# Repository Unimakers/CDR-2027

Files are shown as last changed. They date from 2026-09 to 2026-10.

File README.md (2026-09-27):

# Coupe de France de Robotique 2027 - Unimaker I1/I2

> [!IMPORTANT]
> Ce repo a été créé depuis le template de projet du MakerSpace d'Amiens.
> Les guides d'utilisation du template sont sur le
> [site de documentation du MakerSpace](https://doc.makerspace-amiens.fr/workshops/methodologie-de-projet/).

Ce repo est un site de documentation réalisé par l'équipe des première et deusième années pré-ingénieur de l'école Unilasalle-Amiens, membre de l'association de robotique Unimaker, dans le cadre de leur participation à la Coupe de France de Robotique 2027 (CDR 2027).
Cette documentation sera mise à jour tout au long de l'année à chaque étape du projet.

- **Documentation :** [site du projet](https://unimakers.fr/CDR-2027/) (sources dans [`docs/`](docs/))
- **Fichiers du projet :** [`project/`](project/) (CAO, électronique, code)

## Équipe

### Étudiants de deuxième année

- Ajaz Agbetiafa
- Baptiste Houzelot
- Brett Legret
- Emma Vilain
- Emrick Petit
- Enzo Deviliers
- Gauthier Henriques
- Martin Milon
- Paul Lapeyronnie
- Romain Vantalon
- Samuel Simao

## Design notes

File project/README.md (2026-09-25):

# Fichiers du projet

> [!IMPORTANT]
> **À modifier** : complétez ce README avec ce que contient réellement votre projet.

Ce dossier contient toutes les **sources** du projet. Ce qui s'affiche sur le site
(images, modèle 3D `.glb`, copie des fichiers KiCad) va dans `docs/assets/`.

| Dossier | Contenu |
|---|---|
| [`mcad/`](mcad/) | Conception mécanique : exports STEP, fichiers d'impression 3D et de découpe laser |
| [`ecad/`](ecad/) | Conception électronique : projets KiCad |
| [`firmware/`](firmware/) | Code embarqué (Arduino, ESP32…) |
| [`software/`](software/) | Application sur ordinateur, téléphone ou web |

Supprimez les dossiers qui ne concernent pas votre projet.

**Noms de fichiers :** pas d'espaces ni d'accents (`support-moteur.step`, pas
`Support Moteur.step`), ils cassent les liens du site.

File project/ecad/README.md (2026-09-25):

# Conception électronique

> [!IMPORTANT]
> **À modifier** : décrivez les cartes de votre projet.

Un dossier par projet KiCad (par exemple `carte-principale/`), contenant au minimum
les fichiers `.kicad_pro`, `.kicad_sch` et `.kicad_pcb`.

| Carte | Dossier | Rôle |
|---|---|---|
| Carte principale | `carte-principale/` | Microcontrôleur, alimentation, connecteurs |

Pour afficher une carte sur le site, copiez ses fichiers `.kicad_sch` et `.kicad_pcb`
dans `docs/assets/kicad/`, et recopiez-les quand la carte évolue.

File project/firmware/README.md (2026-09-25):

# Firmware

> [!IMPORTANT]
> **À modifier** : décrivez le firmware de votre projet, ou supprimez ce dossier s'il n'y en a pas.

Le **firmware** est le code qui tourne sur la carte électronique (Arduino, ESP32, Raspberry Pi Pico…).
Il se développe avec **VSCode** et l'extension **PlatformIO**
(voir [Installation de VSCode et PlatformIO](https://doc.makerspace-amiens.fr/docs/tutorials/software/vscode-platformio/installation-vscode/)).

- **Carte cible :** …
- **Bibliothèques :** listées dans `platformio.ini` (`lib_deps`), avec leur version

## Organisation

Un dossier par projet PlatformIO :

```text
firmware/
└── mon-robot/
    ├── platformio.ini    carte, framework, bibliothèques
    ├── src/
    │   └── main.cpp      programme principal
    ├── include/          fichiers .h
    └── lib/              bibliothèques écrites par l'équipe
```

Le dossier `.pio/` (fichiers de compilation) est ignoré par git : ne le commitez pas.

## Compiler et téléverser

1. Dans VSCode, ouvrez le dossier du projet PlatformIO (`File > Open Folder` sur
   `firmware/mon-robot/`), pas la racine du repo : sinon PlatformIO ne détecte pas le projet.
2. Branchez la carte en USB.
3. Dans la barre du bas : **✓** pour compiler, **→** pour téléverser, **🔌** pour ouvrir le moniteur série.

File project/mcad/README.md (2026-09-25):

# Conception mécanique

> [!IMPORTANT]
> **À modifier** : renseignez le lien Onshape et la date du dernier export.

- **Document Onshape :** [lien de partage](https://cad.onshape.com/)
- **Dernier export :** AAAA-MM-JJ

## Contenu

| Fichier / dossier | Contenu |
|---|---|
| `projet.step` | Export STEP de l'assemblage complet (lisible par tous les logiciels de CAO) |
| [`3d-print/`](3d-print/) | Fichiers pour l'impression 3D |
| [`laser-cutting/`](laser-cutting/) | Fichiers pour la découpe laser |

Le modèle 3D affiché sur le site (`.glb`) ne va pas ici mais dans `docs/assets/models/`.

## Exporter depuis Onshape

- **STEP :** clic droit sur l'onglet de l'assemblage > Exporter > format STEP, à enregistrer ici sous `projet.step`.
- **GLB (pour le site) :** même menu, format GLB, à enregistrer dans `docs/assets/models/`.

Réexportez à chaque version importante : Onshape garde l'historique, mais le repo
doit contenir une version utilisable sans compte Onshape.

## Autre logiciel (Fusion, SolidWorks, FreeCAD…)

Déposez ici les fichiers natifs **en plus** de l'export STEP : contrairement à
Onshape, ils ne sont sauvegardés nulle part ailleurs.

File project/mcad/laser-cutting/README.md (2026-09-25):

# Découpe laser

> [!IMPORTANT]
> **À modifier** : complétez le tableau pour chaque pièce, puis supprimez cette ligne.

Déposez ici les fichiers de découpe (`.svg` ou `.dxf`).

| Pièce | Fichier | Matériau | Épaisseur | Quantité |
|---|---|---|---|---|
| Boîtier | `boitier.svg` | Contreplaqué peuplier | 3 mm | 1 |

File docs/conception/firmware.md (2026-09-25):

---
layout: default
title: Firmware
parent: Conception
nav_order: 3
---

# Firmware

{: .a_supprimer }
> Le **firmware** est le code qui tourne sur la carte électronique (Arduino, ESP32,
> Raspberry Pi Pico…) : il lit les capteurs, pilote les actionneurs, gère les
> communications. Supprimez cette page si votre projet n'en a pas.
> Si le code est conséquent, faites une sous-page par fonction (par exemple
> « Asservissement moteur », « Communication Bluetooth »).
> Voir [Documenter son code et son firmware](https://doc.makerspace-amiens.fr/workshops/methodologie-de-projet/tutorials/documenter-code-firmware/).

## Architecture du code

{: .a_modifier }
> Fonctionnement général : boucle principale, machine à états, interruptions.
> Un schéma (diagramme d'états, organigramme) aide beaucoup.

## Environnement

{: .a_modifier }
> Carte cible, framework (Arduino, ESP-IDF…), bibliothèques principales et leur rôle.
> Le projet se développe avec VSCode et PlatformIO : la procédure pour compiler
> et téléverser est dans le README du dossier firmware.

[📁 Code du firmware]({{ site.gh_edit_repository }}/tree/main/project/firmware){: .btn }

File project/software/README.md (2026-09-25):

# Software

> [!IMPORTANT]
> **À modifier** : décrivez l'application de votre projet, ou supprimez ce dossier s'il n'y en a pas.

Le **software** est l'application qui tourne sur un ordinateur, un téléphone ou un
navigateur (interface de contrôle, traitement de données…).

- **Langage :** …
- **Dépendances :** …

## Installer et lancer

1. …

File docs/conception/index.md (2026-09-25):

---
layout: default
nav_order: 5
title: Conception
has_children: true
---

# Conception

{: .a_supprimer }
> **Une page par sous-système, pas une seule page pour toute la conception.**
> Ce template propose un découpage par domaine (mécanique, électronique,
> firmware, software) avec un exemple de sous-système dans les deux premiers. Adaptez-le à votre projet :
> - dupliquez une page d'exemple pour chaque sous-système (pince, châssis, carte capteurs…) ;
> - renommez ou supprimez les domaines qui ne vous concernent pas ;
> - si votre projet s'y prête mieux, découpez d'abord par sous-système, puis par domaine.
>
> Une sous-page se déclare avec `parent:` (et `grand_parent:` au niveau en dessous)
> dans son en-tête : inspirez-vous des pages d'exemple.

## Architecture globale

{: .a_modifier }
> Présentez le projet découpé en sous-systèmes : un schéma bloc (image) et une phrase
> par bloc suffisent. Qui communique avec qui ? Qu'est-ce qui alimente quoi ?
> Exemple : le schéma ci-dessous est écrit en texte avec [Mermaid](https://mermaid.js.org/) :
> modifiez-le directement dans le fichier, ou remplacez-le par une image réalisée
> avec l'outil de votre choix (draw.io, Inkscape, papier scanné…).

```mermaid
graph LR
    Batterie[Batterie] --> Carte[Carte principale]
    Capteur[Capteur de couleur] --> Carte
    Carte --> Moteur[Moteur du trieur]
    Carte <-->|Bluetooth| Appli[Application mobile]
```

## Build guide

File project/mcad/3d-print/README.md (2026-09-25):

# Impression 3D

> [!IMPORTANT]
> **À modifier** : complétez le tableau pour chaque pièce, puis supprimez cette ligne.

Déposez ici les fichiers prêts à imprimer (`.3mf` de préférence, il conserve les réglages du slicer).

| Pièce | Fichier | Matériau | Buse | Couche | Remplissage | Supports | Quantité |
|---|---|---|---|---|---|---|---|
| Support moteur | `support-moteur.3mf` | PLA | 0,4 mm | 0,2 mm | 20 % | Non | 2 |

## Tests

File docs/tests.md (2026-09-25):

---
layout: default
nav_order: 7
title: Tests et résultats
---

# Tests et résultats

{: .a_supprimer }
> Cette page apporte la **preuve** que votre projet répond au cahier des charges.
> Reprenez les critères de la page **Objectifs du projet** et écrivez un protocole
> de test pour chacun, puis notez les résultats, **y compris les échecs**.
> Voir [Documenter les tests et résultats](https://doc.makerspace-amiens.fr/workshops/methodologie-de-projet/tutorials/documenter-tests-resultats/).

## Synthèse

{: .a_modifier }
> Un tableau récapitulatif des critères testés. Exemple :

| Critère | Attendu | Mesuré | Validé |
|---|---|---|---|
| Taux de tri correct | ≥ 80 % sur 20 essais | 85 % | ✅ |
| Autonomie sur batterie | ≥ 4 h | 3 h 30 | ❌ |

## Test : taux de tri correct

{: .a_modifier }
> Exemple de protocole : dupliquez cette section pour chaque critère testé.

**Critère visé :** ≥ 80 % sur 20 essais (voir le cahier des charges).

**Méthode :** déposer 20 déchets connus un par un, noter la catégorie détectée.

**Conditions :** éclairage de la salle d'exposition, température ambiante.

| Essai | Déchet réel | Détection | Correct ? |
|---|---|---|---|
| 1 | Plastique | Plastique | ✅ |
| 2 | Verre | Métal | ❌ |
| … | … | … | … |

**Résultat :**

$$
\tau = \frac{n_{\text{corrects}}}{n_{\text{essais}}} = \frac{17}{20} = 85\,\%
$$

Critère atteint. Les 3 erreurs concernent des bouteilles en verre teinté.

## Test : autonomie sur batterie

{: .a_modifier }
> Les formules s'écrivent en LaTeX entre `$$` : seules sur leur ligne (avec une
> ligne vide avant et après) elles sont centrées, dans une phrase elles restent
> dans le texte. Le `$` simple ne fonctionne **pas** sur le site.

Avec une batterie de capacité $$C = 2000\ \text{mAh}$$ et un courant moyen
mesuré de $$I_{\text{moy}} = 570\ \text{mA}$$, l'autonomie théorique vaut :

$$
t = \frac{C}{I_{\text{moy}}} = \frac{2000}{570} \approx 3{,}5\ \text{h}
$$

Mesurée : 3 h 30, critère non atteint (≥ 4 h). Piste : mise en veille du capteur
entre deux déchets.

{% include graphique.html csv="assets/data/decharge-batterie.csv" titre="Décharge de la batterie" y="Tension (V)" %}

{: .a_modifier }
> Le graphique est tracé à partir du fichier `docs/assets/data/decharge-batterie.csv` :
> première colonne pour l'axe X, une colonne par courbe, les noms des colonnes
> servent de légende. Exportez vos mesures en CSV (tableur, moniteur série…),
> placez le fichier dans `docs/assets/data/` et changez le nom dans l'include.
> Options : `type="bar"` pour un histogramme, `type="scatter"` pour des points seuls.

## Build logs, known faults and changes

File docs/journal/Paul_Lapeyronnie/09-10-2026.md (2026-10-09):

---
layout: default
title: "09-10-2026 : lancement"
parent: Paul_Lapeyronnie
grand_parent: Journal de bord
---

# carte élec
### j'ai mis les pins dans le bon ordre pour avoir aucun croisement et ça rend bien.
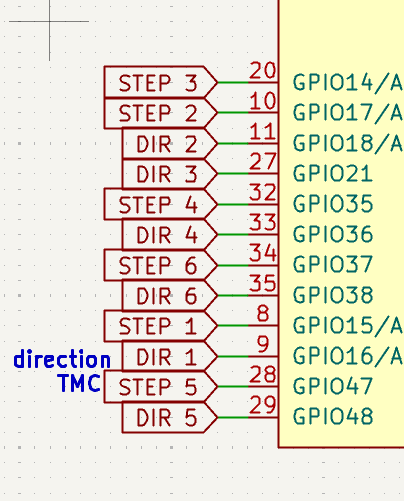
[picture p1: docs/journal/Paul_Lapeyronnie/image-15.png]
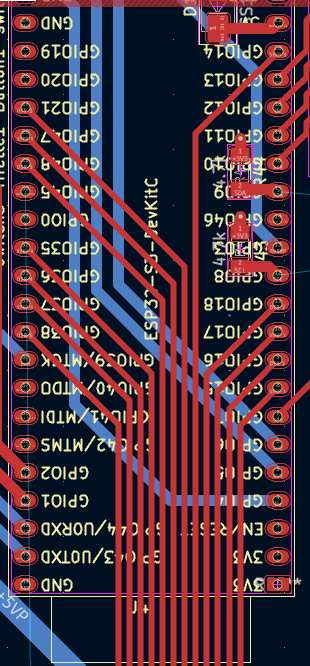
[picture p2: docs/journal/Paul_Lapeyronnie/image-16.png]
### 

### j'ai aussi relierles dernier élément comme ecrans, sda scl, tirette boutton ..., Eneble.

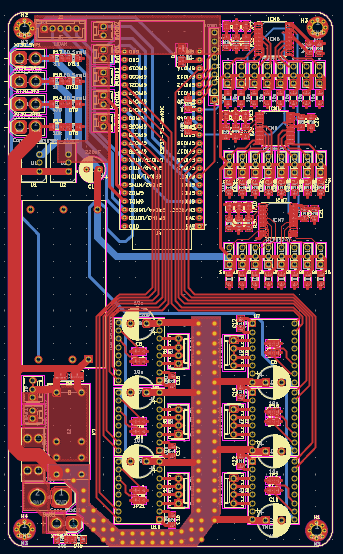
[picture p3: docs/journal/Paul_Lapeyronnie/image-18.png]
### 
### victoire !!! (jai pas encore verif avec alban)
### j'ai demandé a alban c'est pas fini j'ai des truc a faire :=(
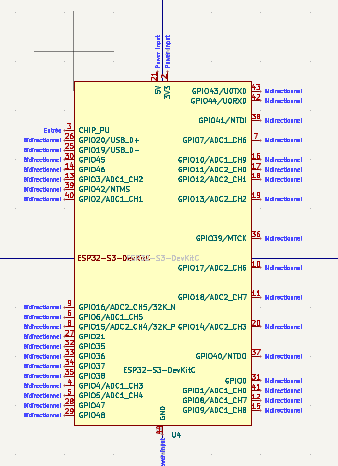
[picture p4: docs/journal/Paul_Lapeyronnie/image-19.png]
### 
### j'ai modif tous les pins pour que cela arrive de manière logique sur le routage

## ce dont je ne suis pas trop content
- le détoure du enable n'est pas beau 
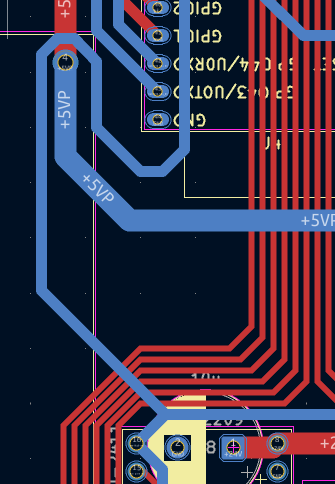
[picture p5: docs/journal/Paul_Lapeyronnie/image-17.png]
### 
- sda scl fait un détoure chelou

# module devkit c1
## y a t'il de pins spi non utilisable ?
### non après avoir regarder la datasheet, les pins 27 a 35 sont utiliser pour la psram/ quad spi flash, mais ils ne sont pas connecter au pins du module donc pas d'inquiétude 
### chill

## fun fact
### dans le module Esp il y a le vrais composant esp ainsi que des composants basique qui permettent de faire fonctionner le composant esp, le module contien aussi une antenne et un blindage pour les composants afin d'empecher le cristal de ce prendre les rayonnement de l'entaine.
### le composant de base esp a plein de pin gpio, usb, gnd, 3v3 ... ainsi que une certaine quantitée de mémoire ram et flash. Si on en veux plus, on doit utiliser des pin (gpio) pour en ajouter par exemle sur le devkit, on utilise : 
- sck = clok
- sdi = com
- sdo = com
- sc = select
### comme on utilise ces pin pour ajouter de la mémoire on ne peut pas les utiliser pour autre chose sans modifier la mémoire flsh/ram, sur le devkit ils ne sont pas relier au pins externes

# fun fact
### les via c'est en 0.7, 0.4 !

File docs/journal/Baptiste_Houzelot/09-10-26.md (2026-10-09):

---
layout: default
title: 09-10-26
parent: Baptiste_Houzelot
has_children: true
---

# Realisation du schema de l'actionneur
## Matériels nécessaires : 
- 1 cervo-moteur 
- 2 pompes 
- 1 moteur stepper
- 1 courroie

## Idées : 
### Prendre 3 cartons en une fois avec les pompes, tourner le support des pompes selon quel construction on doit faire et les placer. 
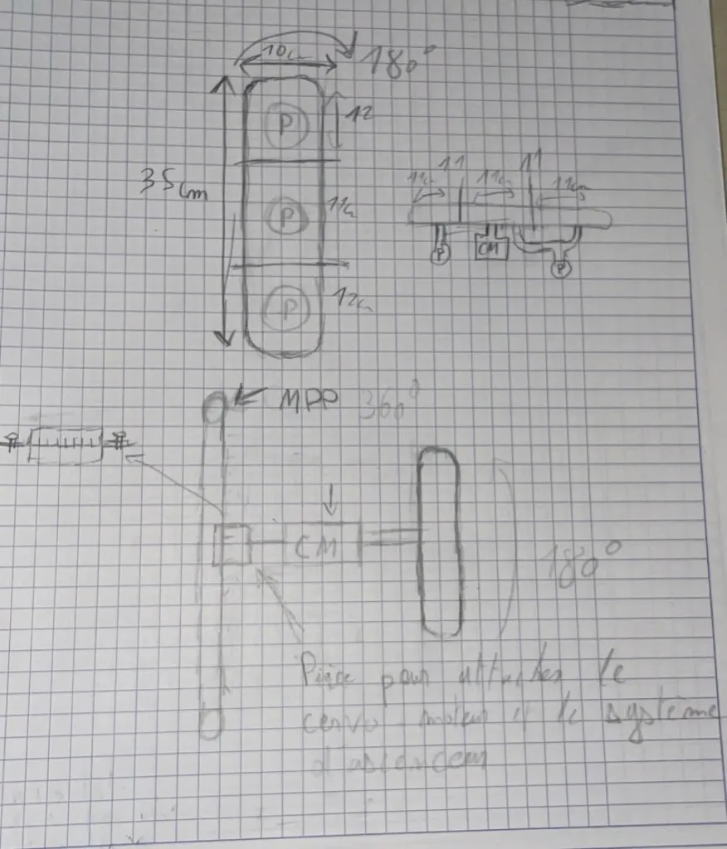
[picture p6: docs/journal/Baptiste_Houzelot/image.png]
###

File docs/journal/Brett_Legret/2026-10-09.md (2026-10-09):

---
layout: default
title: "2026-10-09 : conception d'actionneur version final" 
parent: Brett_Legret
grand_parent: Journal de bord
---

# 2026-10-09 : Conception de l'actionneur version final avant la modélisation:
---

a séance a débuté par une analyse de l'environnement de jeu de l'édition 2027.
⚬	Nous avons utilisé un simulateur 3D en ligne (visible dans le fichier Capture d’écran 2026-10-09 à 09.47.34.png) pour visualiser la table, les zones de départ et l'agencement des éléments de jeu.
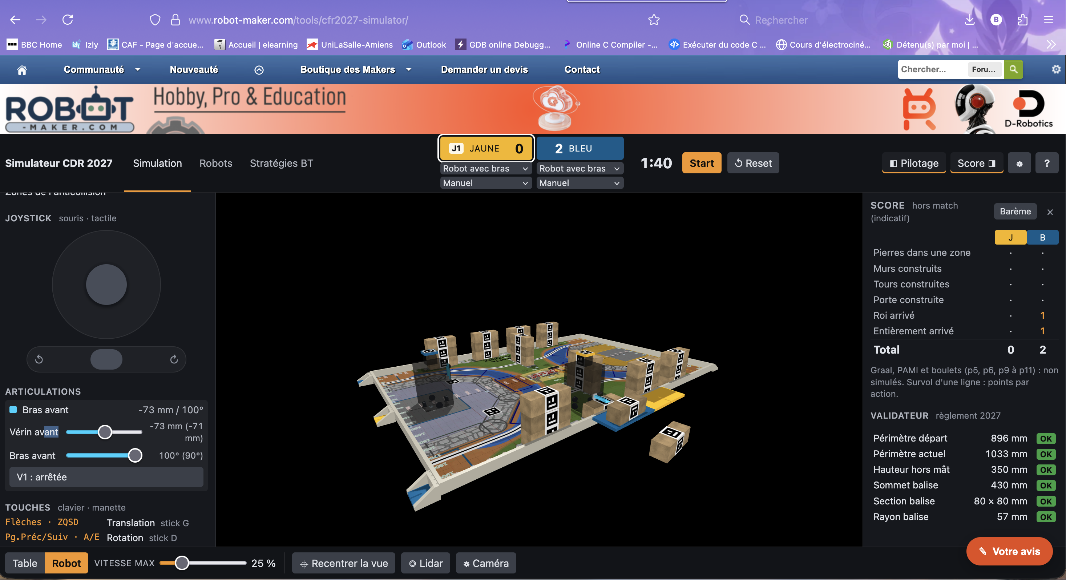
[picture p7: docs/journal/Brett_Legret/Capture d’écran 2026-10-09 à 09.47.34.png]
### 
⚬	Afin de bien cibler nos actions et d'éviter les erreurs, nous avons réétudié le règlement officiel "Eurobot2027_Rules_FR.pdf" (comme le montre le fichier Capture d’écran 2026-10-09 à 09.52.19.png). Nous nous sommes concentrés particulièrement sur la figure 6 détaillant le plan de construction du château avec les blocs.
2. Idéation et conception de l'actionneur
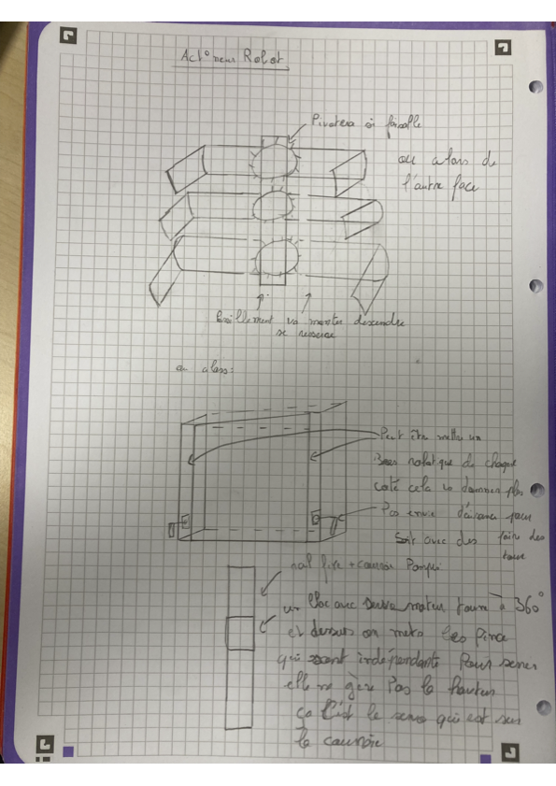
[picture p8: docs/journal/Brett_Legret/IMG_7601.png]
### 
Pour répondre aux défis imposés par le terrain, la deuxième partie de la séance a été consacrée au brainstorming sur le système mécanique du robot. Plusieurs concepts ont été dessinés et documentés sous le titre "Actionneur Robot". Voici les trois idées principales qui ont émergé :
⚬	Concept A (Mécanisme central) : Un système de préhension capable de se resserrer pour attraper les objets, de monter et descendre, avec l'idée d'ajouter un pivot ("pivotera si faisable") ou d'agir depuis "l'autre face".
⚬	Concept B (Bras latéraux) : Une structure en forme de boîte proposant d'intégrer un bras robotique de chaque côté. Cette configuration aurait pour but de donner davantage d'aisance au robot pour effectuer des rotations.
⚬	Concept C (Rail et courroie - Piste privilégiée) : L'utilisation d'un rail fixe couplé à une courroie. Le concept repose sur un bloc équipé d'un servomoteur capable de tourner à 360°, sur lequel reposent des pinces indépendantes. L'avantage de ce système est de séparer les efforts : les pinces gèrent uniquement le serrage, tandis que la hauteur n'est pas gérée par les pinces mais par un système sur la courroie.
3. Choix des composants et motorisation de l'actionneur
Pour donner vie à notre concept de préhension sur rail (Concept C), nous avons défini la nomenclature des moteurs nécessaires. Il nous faudra au total 6 moteurs, avec des rôles bien distincts pour séparer les efforts :
⚬	Élévation (2 moteurs pas à pas) : Nous utiliserons deux moteurs pas à pas dont le rôle exclusif sera de faire monter et descendre le système via la poulie et la courroie sur le rail fixe.
⚬	Rotation et Préhension (4 servomoteurs) : Ces moteurs seront embarqués sur le bloc mobile et serviront à manipuler les objets :
⚬	Faire pivoter le bloc pour orienter les pièces.
⚬	Serrer les pinces pour attraper les éléments de jeu de façon indépendante.
Bilan de la séance :
Nous avons une vision claire des objectifs (manipulation et empilage pour le château) et nous avons posé des bases mécaniques solides pour l'actionneur. La prochaine étape sera de commencer à modéliser ce système pour intégrer les 6 moteurs.

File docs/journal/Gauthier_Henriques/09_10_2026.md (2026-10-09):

---
layout: default
title: "08-10-2026 : Code robot principale"
parent: Gauthier_Henriques
grand_parent: Journal de bord
---

# 07-10-2026 : Dev

**Séance :** programé · **Durée :** 3h

## QUI FAIT QUOI
    - BRETT : actionneur
    - BAPTISTE : actionneur

Note sur les actionneurs pour préparer le code
    - 4 stepper pour les actionneurs
    - 24 servo / pompe total répartit sur 3 lignes de 8
    - un code actionneur, contrôle tout type

Note code: rester modulaire, multifichier, 
- étape 1 : rouler 
- étape 2 : LiDar
- étape 3 : tirette
- étape 4 : Actionneur
- étape 5 : switch (potentiellement avec 2/4)
- étape 6 : screen si on a le temps, pas obligatoire

Spi : buse de com
- SCK transfer clock
- SDI : input 
- SDO : output
- CS : chip select
Cahque elmeent sur le bus à un CS, microco a flash (stockage) et ram (vive) 
on peut ajouter de la psram (augmenter ram)
Quad SPI limite vitesse de com - donc octal SPI (8 lignes de donnés, 11 broches ) donc on mange sur Gpio
dans module wroom - composant esp32 s3 (on a pas le matos pour souder le composant donc on achete le module [valider par espressif])

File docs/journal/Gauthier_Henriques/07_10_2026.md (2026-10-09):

---
layout: default
title: "07-10-2026 : Code robot principale"
parent: Gauthier_Henriques
grand_parent: Journal de bord
---

# 07-10-2026 : Dev

**Séance :** Contrat-d'étude · **Durée :** 1 h 30

## Différence software vs firmware :
> software : haut niveau, fonctionne sur un OS.
> firmware : software de bas niveau, fonctionne de façon permanente ou semi-permanente sur un microcontroleur, controle les fonctions core du dit.

## Fait :
J'ai mis en place une config modulable pour le robot principale. Afin que tout les actionneurs puisse être tranférer sans probleme

Fichier : [`project/firmware/Firmware_Robot_Principale/src/config.h`](https://github.com/Unimakers/CDR-2027/blob/main/project/firmware/Firmware_Robot_Principale/src/config.h)

```mermaid
flowchart LR
    ESP[ESP32-S3<br/>config.h] --> STP[6x TMC2209<br/>STEP / DIR]
    ESP --> PWR[EN 5VP<br/>servos]
    ESP --> I2C[I2C<br/>3x PCF8574]
    ESP --> TFT[Écran TFT<br/>SPI]
    ESP --> IN[Tirette, bouton,<br/>3 switchs]
    ESP --> LID[LiDAR LD06<br/>UART + PWM]
```

```cpp
// Configuration file for the robot firmware
// Pin names come from the KiCad schematic "carte principale" (ESP32-S3-DevKitC, U4).
// All pins are placeholders (-1) until assigned; the schematic GPIO is given in the comments.

#pragma once

// Serial debug output
#define DEBUG_SERIAL true

// match duration
#define MATCH_DURATION 100 // in seconds

// ---------------------------------------------------------------------------
// Stepper drivers (TMC2209 U5..U10, 24V), driven with FastAccelStepper
// Pins are meant for engine.stepperConnectToPin(STEP_x_PIN) and
// stepper->setDirectionPin(DIR_x_PIN). The TMC2209 ~EN pins are not wired to the ESP32.
// ---------------------------------------------------------------------------
#define STEPPER_COUNT 6

#define STEP_1_PIN -1 // schematic: GPIO14
#define DIR_1_PIN -1  // schematic: GPIO17
#define STEP_2_PIN -1 // schematic: GPIO18
#define DIR_2_PIN -1  // schematic: GPIO21
#define STEP_3_PIN -1 // schematic: GPIO35
#define DIR_3_PIN -1  // schematic: GPIO36
#define STEP_4_PIN -1 // schematic: GPIO37
#define DIR_4_PIN -1  // schematic: GPIO38
#define STEP_5_PIN -1 // schematic: GPIO15
#define DIR_5_PIN -1  // schematic: GPIO16
#define STEP_6_PIN -1 // schematic: GPIO47
#define DIR_6_PIN -1  // schematic: GPIO48

// Motion parameters (placeholders)
#define STEPPER_STEPS_PER_REV -1       // full steps per motor revolution
#define STEPPER_MICROSTEPS -1          // set by the TMC2209 MS1/MS2 configuration
#define STEPPER_MAX_SPEED_HZ -1        // for setSpeedInHz(), in steps/s
#define STEPPER_ACCELERATION -1        // for setAcceleration(), in steps/s^2

// ---------------------------------------------------------------------------
// Power
// ---------------------------------------------------------------------------
#define EN_5VP_PIN -1 // enable of the 5VP (servo) converter, schematic: GPIO3

// ---------------------------------------------------------------------------
// I2C bus (3x PCF8574T I/O expanders ICM6..ICM8, J2 connector)
// ---------------------------------------------------------------------------
#define I2C_SDA_PIN -1 // schematic: GPIO9
#define I2C_SCL_PIN -1 // schematic: GPIO8

// PCF8574 addresses (set by the A0..A2 jumpers)
#define PCF_ICM6_ADDR -1
#define PCF_ICM7_ADDR -1
#define PCF_ICM8_ADDR -1

// ---------------------------------------------------------------------------
// TFT screen (J1, SPI, no reset line on the schematic)
// ---------------------------------------------------------------------------
#define TFT_MISO_PIN -1 // "sdo", schematic: GPIO7
#define TFT_MOSI_PIN -1 // "sdi", schematic: GPIO11
#define TFT_SCK_PIN -1  // "sck", schematic: GPIO10
#define TFT_DC_PIN -1   // "dc",  schematic: GPIO12
#define TFT_CS_PIN -1   // "cs",  schematic: GPIO13

// ---------------------------------------------------------------------------
// Inputs
// ---------------------------------------------------------------------------
#define TIRETTE_PIN -1 // starting cord, "tir", schematic: GPIO2
#define BUTTON_PIN -1  // push button, "bu", schematic: GPIO4
#define SWITCH_1_PIN -1 // "sw1", schematic: GPIO5
#define SWITCH_2_PIN -1 // "sw2", schematic: GPIO6
#define SWITCH_3_PIN -1 // "sw3", schematic: GPIO1

// ---------------------------------------------------------------------------
// LIDAR (J5, LD06 library in src/ld06.h)
// The LD06 is wired on the ESP32 UART0 pins (GPIO43/44), shared with the USB-UART bridge.
// Constructor: LD06(HardwareSerial &serial, LD06_PWM_PIN); init() calls serial.begin(230400) itself.
// ---------------------------------------------------------------------------
#define LD06_PWM_PIN -1 // motor PWM, "pwm", schematic: GPIO39 (255 = no PWM pin for the library)
#define LD06_RX_PIN -1  // ESP32 RX <- LD06 TX, schematic: GPIO44 (U0RXD)
#define LD06_TX_PIN -1  // ESP32 TX -> LD06 RX, schematic: GPIO43 (U0TXD)
#define LD06_UART_NUM -1 // HardwareSerial number to use for the LIDAR
#define LD06_BAUDRATE 230400 // fixed by the LD06 and by LD06::init()

// Filtering (see setDistanceRange / setAngleRange / setIntensityThreshold)
#define LD06_MIN_DISTANCE -1  // in mm
#define LD06_MAX_DISTANCE -1  // in mm
#define LD06_MIN_ANGLE -1     // in degrees
#define LD06_MAX_ANGLE -1     // in degrees
#define LD06_INTENSITY_THRESHOLD -1 // 0-255
#define LD06_UPSIDE_DOWN false

// Lidar position relative to the robot center (see setOffsetPosition)
#define LD06_OFFSET_X -1     // in mm
#define LD06_OFFSET_Y -1     // in mm
#define LD06_OFFSET_ANGLE -1 // in degrees
```

### Arrivant I1 mercredi soir 

- CARTIER Colin I1
- DEKER Leo I1
- ANDRADE Henrique I1
- ASSI Nassimi I1
- LECERF Thomas I1
- FONTENIER Eliott B1
- JOSEPH-MERISIER Handy B1
- ROELENS Gabriel I3 PARA FISE

## PENSE BÊTE
KALEMAN 
SENSOR FUSION
sick

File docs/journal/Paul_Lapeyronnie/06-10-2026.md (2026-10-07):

---
layout: default
title: "06-10-2026 : lancement"
parent: Paul_Lapeyronnie
grand_parent: Journal de bord
---
# confirmer carte
- au lieu faire des routes de 8mm faire des zones avec plein de via 
### 
- mettre les bon pin pour l'esp / step, dir 
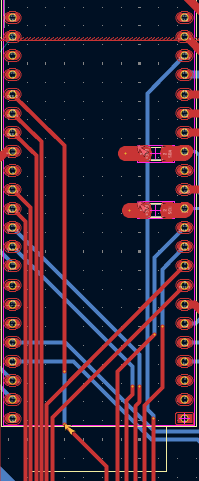
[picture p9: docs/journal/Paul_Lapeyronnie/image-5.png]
### 
- ne jamais mettre 2 via sur la meme route 
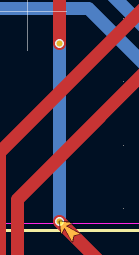
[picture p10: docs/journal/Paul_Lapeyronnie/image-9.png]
### 
- préférer metre un via proche plutot que de relier avec route elle meme reliée a via 
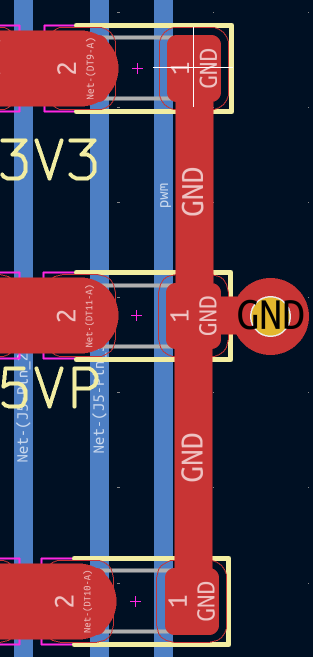
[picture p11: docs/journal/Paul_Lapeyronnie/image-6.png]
### 
- quand les routes s'entremèllent on peut parfois tourner le tout 
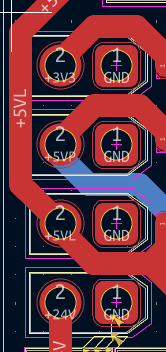
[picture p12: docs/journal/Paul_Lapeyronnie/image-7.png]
### 
- ne pas mettre des bumper sur trace de la carte 
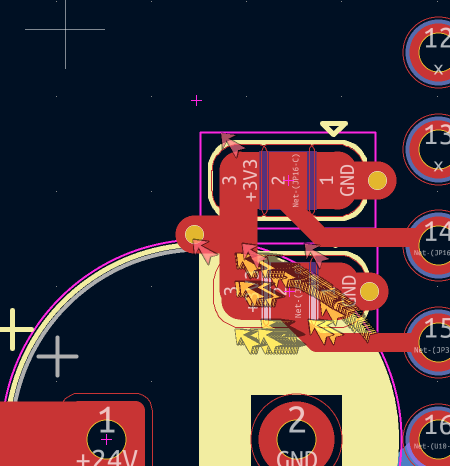
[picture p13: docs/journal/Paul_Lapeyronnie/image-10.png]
### 
- mettre toutes les empruntes a la grille 
- si éléments se répèttent mettre tout (routes) dans le meme sens bien aligner

# modelisation 3D
## infos entrée

### j'ai intégrer l'enssemble des infos d'entree :
- 3 switch
- 1 bouton
- 1 BAU
- 1 tirette
- 1 connecteur usb
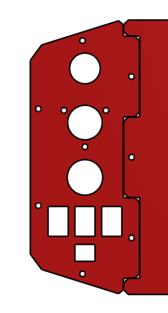
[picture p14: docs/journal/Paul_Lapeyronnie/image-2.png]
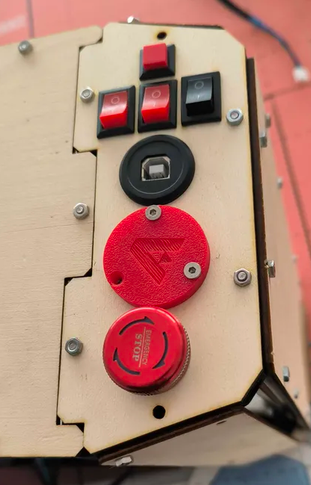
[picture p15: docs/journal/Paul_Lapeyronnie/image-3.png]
###   

## compartiment carte
### fair la meme chause qu'avec la batterie pour la carte elec
### problème pour le grall coté pas lisse
### pratique pour modif / regarder l'élec
### possibilité de juste faire un tiroire mais caché deriere la plaque principale pleine (on dévice la plque pendant les teste et on la remet lors des match)
### fait ça c'est bien
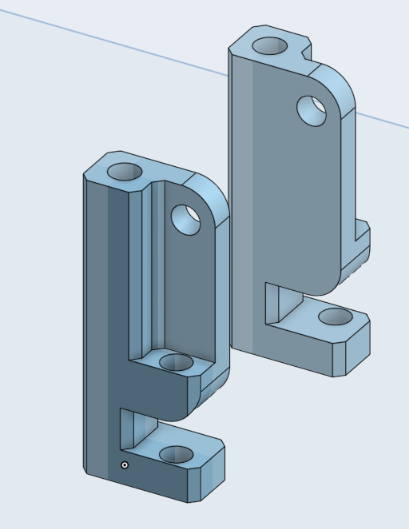
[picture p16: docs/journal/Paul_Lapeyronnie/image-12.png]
### 
### voila !
### le support repose sur un point d'accroche de chaque coté permettant de faire pivoter l'enssemble de la carte pour bloquer la carte a l'horizontal, on met une visse dans le second trou et cela vien en buté contre une 3e visse qui elle était sur la makerbim
### je pense que la carte sera trop fragile pour tenir sans fléchir, je pense donc qu'une armature a l'arière de la carte sera utile. ainsi la carte cera entièrement stable.
### il manque aussi un moyen d'arreter la carte quand elle est a la verticale

### cela permet d'agir sur le programme du robot, le but du positionement est de placer l'enssemble de manière accessible et optimiser. les switch sont cote cote et permettent de choisir la stratégie du robot, le BAU est a l'une des extrémitée pour etre le plus acessible possible, sur l'un des coté, on est pas dérangé par le mat du lidar cela permet donc a l'arbitre de l'apuiller simplement. la tirrette est a coté du BAU car c'est la deuxieme chause qu'on touche après avoir allumer le robot , elle permet d'activer le robot avec un aimant. le connecteur usb est au centre car c'est celui dont on a le moin besoin d'accéder en match, il permet de se brancher directement sur l'espp sans avoir a tirer un cable depuis le port usb de l'ESP. enfin de bouton permet soit delancer l'initialisationn du robot soit de séléctionner des choses sur l'écran au chois.

### j'ai placer les éléments sur onshape en fesant la modélisation 3D de la plaque et en ajoutant des trous aux bonnes dimmentions pour chaqu'un des éléments. enfin j'ai exporté en dxf puis découpé a la découpeuse laser la plaque dans du bois de 3mm

# fun fact
### au lieu faire des routes de 8mm fait des zones, pareil quand il des petites route qui font des ziguigui partout des que il y a plusieurs pins raprochés en générale on met une zone. Si on fait passer beaucoup de puissance, on met des via partout et on duplique la zone dans la couche inf

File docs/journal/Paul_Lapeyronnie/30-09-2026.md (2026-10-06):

---
layout: default
title: "30-09-2026 : lancement"
parent: Paul_Lapeyronnie
grand_parent: Journal de bord
---
 
## Carte élec :
- mon début de carte a des boucle + pistes trop longue.
- servo correcte ne pas refaire.
- attention manque un condo de découplage sur servo
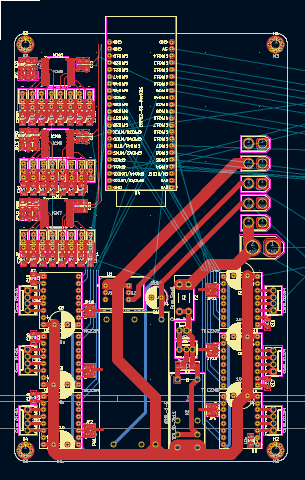
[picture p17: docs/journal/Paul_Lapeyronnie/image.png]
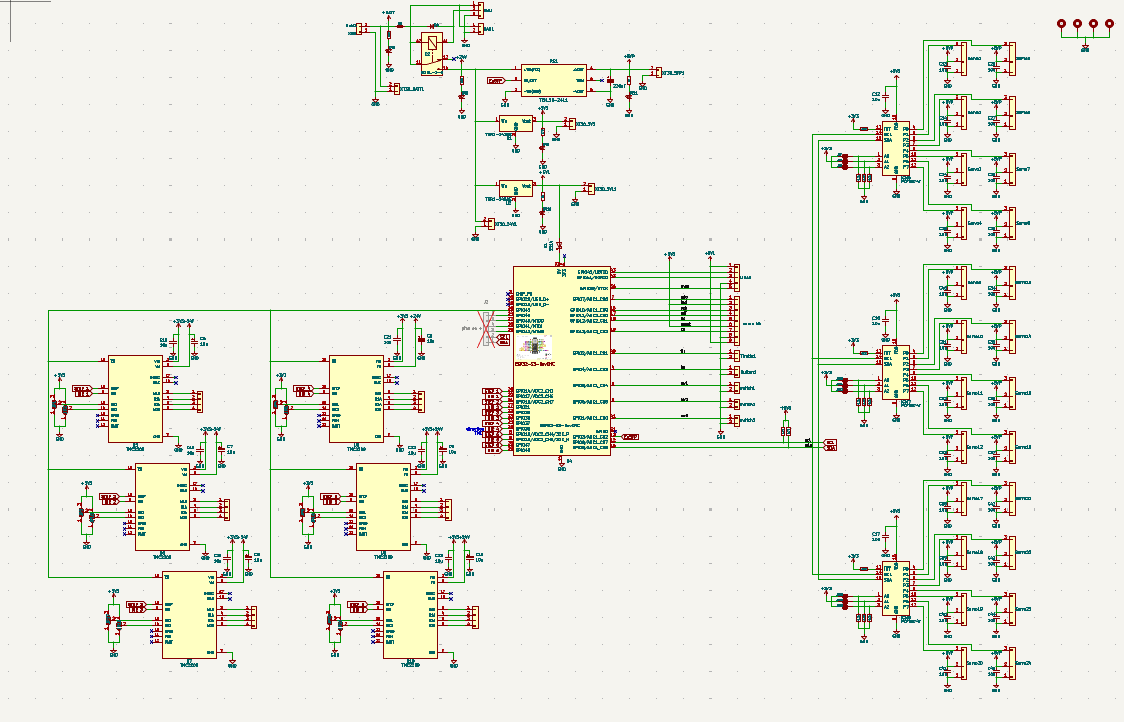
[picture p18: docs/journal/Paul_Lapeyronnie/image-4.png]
###  

- possible mettre puissance et tmc sur une couche, coller tmc coté conn, faire passer alim au milieu et mettre puissance bat a coté.

- modif pin de l'esp pour tout metre facilement sur le routage

## truc intéressant :
- carte multi couche  
 . mettre les signaux sur les couches externes et la puissance a l'intérireure, avec gnd au cul de la couche signal la plus importante.
 . si besoin de piste plus fine peut doubler piste sur deux couche de la carte ! la bombarder de via ! 
 . possible de mettre des composants au milieu
 . possible de mettre des couche vide pour faire passer du liquide a l'intérieur

- revetement de carte: 
(j'ai oublié les noms)
. plaqué or 

. on met de l'éteint partout puis on le fix aux endroits souhaités et enfin on viens soufler le sur plus

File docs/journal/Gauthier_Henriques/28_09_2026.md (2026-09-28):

---
layout: default
title: "28-09-2026 : Gestion de projet"
parent: Gauthier_Henriques
grand_parent: Journal de bord
---

# 28-09-2026 : Cours gestion de projet

**Séance :** planifiée · **Durée :** 1h 30 min

## Fait

-   Découverte de la méthode en V
-   8mb.video
-   Rédaction du cahier des charges du robot principal :

```
01 qui : L'équipe UniMakers vas l'utiliser en manque de sommeil, stress intense, pendant la coupe de FRANCE de robotique
02 pour quoi faire : - Le robot doit bouger pour marquer au moins 1 point
                     - le robot principale doit récupérer des blocs en carton pour construire des murs et tours d'un chateau.
                     - Il doit rentrer à sa base à la fin.
                     - Il doit pouvoir reperer ses alentours
03 comment saura-t-on que c'est réussi: 
     - Il faut qu'il soit dans ça base avant 100 secondes suivant le début du match
     - Il doit marquer au moins un point
     - Il doit avoir un chateau autour de lui à la fin
     - Le robot ne doit pas percuter un mur ou un autre robot
     - Se lancer à chaque tire de tirette
```

## Pourquoi

-   Réponse au besoin du robot principal.

## Reste à faire

-   Mettre en commun le cahier des charges avec le reste de l'équipe afin de confirmer nos objectifs et notre cahier des charges.

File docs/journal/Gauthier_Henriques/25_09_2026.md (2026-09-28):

---
layout: default
title: "25-09-2026 : Création journal de bord"
parent: Gauthier_Henriques
grand_parent: Journal de bord
---

# 25-09-2026 : Création journal de bord

**Séance :** planifiée · **Durée :** 3 h

## Fait

**Mise en place :**

-   Repo github de la cdr 2027, du journal de bord de tous les I2 participent.
-   Remodélisation de l'IMU du robot pricipal :
    -   Passage de 1 à trois switch, ajout d'un adaptater de connexion à l'esp32
-   Mise en place des stratégies pricipales des robots
-   Brainstorm sur actionneur, mise en place des DDL et besoin.

**Equipe**

-   Explication des roles au I2.
-   Dispatch des roles au sein des I2.

## Pourquoi

-   Il faut lancer les équipes en s'assurant qu'ils aient toutes les explications

## Reste à faire

-   Finir la carte électronique avec Paul.
-   Continuer mon draft d'actionneur.

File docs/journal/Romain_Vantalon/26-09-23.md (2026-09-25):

---
layout: default
title: "2026-09-23 : création d'élèments de jeu"
parent: Martin_Milon
grand_parent: Journal de bord
---

# 2026-09-25 : création d'élèments de jeu

## Fait

préparation des éléments de jeu (cartons pour carrière de pierre), ajustement des mesure pour convenir (meilleur mais reste à améliorer, le coté de fermeture à un jeu de 5 mm)

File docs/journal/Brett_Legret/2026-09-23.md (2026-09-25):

---
layout: default
title: "2026-09-25 : conception d'actionneur" 
parent: Brett_Legret
grand_parent: Journal de bord
---

# 2026-09-25 : Conception de l'actionneur :
---

Périmètre retenu (V1)

Construire les murs (3 pierres empilées à plat)
Poser les 2 pierres verticales de la porte
La 3ᵉ pierre (horizontale, sommet de la porte) est hors scope pour l'instant

Architecture

1 axe vertical : colonne (tiges/rails de guidage + courroie crantée ou vis), 1 moteur pas à pas NEMA17 + driver TMC2209
Pas de bras articulé, pas de cinématique inverse : le châssis du robot gère le XY, la colonne ne gère que la hauteur
Positions préprogrammées en dur : niveau 1/2/3 du mur (~110/220/330mm), position porte (~160mm, point médian de la pierre debout)

Pince

Serrage latéral sur les grandes faces (320×110mm) de la pierre — jamais par en dessous
1 servo FS5115M + mécanisme à crémaillère double : pignon central entraîné par le servo, deux crémaillères opposées → ouverture/fermeture symétrique des mors sans code de synchronisation
Guidage des crémaillères nécessaire (rails/tiges) pour éviter le désalignement
Ouverture/fermeture toujours horizontale pour ne jamais buter contre les pierres déjà posées en dessous

Pose du mur (à plat)

Descente → contact avec la pierre du dessous → ouverture latérale des mors → remontée dégagée

Pose de la porte (debout)

Pierre saisie directement dans son orientation debout dans la carrière (pas de rotation)
Serrage au centre de gravité (~160mm de haut) pour éviter le basculement pendant le transport
Pose : descente jusqu'au contact avec le sol → ouverture latérale → remontée
Risque identifié : pierre haute (320mm) sur base étroite (110×110mm) → peut basculer seule. Piste à creuser : guide passif au sol ou garantir un guidage vertical sans jeu

Contraintes règlement validées

Toutes les hauteurs manipulées (≤330mm) restent sous la limite des 350mm → pas de souci réglementaire pour cette V1
Gabarit robot (≤1200/1400mm) largement suffisant pour loger colonne + pince

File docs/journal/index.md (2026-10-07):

---
layout: default
title: Journal de bord
nav_order: 9
has_children: true
---

# Journal de bord

{: .a_supprimer }
> Chaque membre de l'équipe tient **son propre** journal : une page par séance de
> travail, pendant les heures prévues **ou en dehors**. 5 à 10 minutes en fin de
> séance suffisent.
>
> **Ajouter une séance :**
> 1. copiez le fichier `docs/journal/_modele-seance.md` dans **votre** dossier
>    (par exemple `docs/journal/etudiant-1/`) ;
> 2. renommez la copie avec la date du jour : `2026-09-23.md` ;
> 3. remplissez l'en-tête (`title`, `parent`) et les trois rubriques.
>
> Commencez le titre par la date au format `AAAA-MM-JJ` : les séances
> s'afficheront alors dans l'ordre chronologique dans le menu.
>
> Voir [Tenir un journal de bord](https://doc.makerspace-amiens.fr/workshops/methodologie-de-projet/tutorials/journal-de-bord/).

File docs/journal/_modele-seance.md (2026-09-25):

---
layout: default
title: "AAAA-MM-JJ : sujet de la séance"
parent: Prénom Nom
grand_parent: Journal de bord
---

<!--
Modèle de séance, ce fichier n'apparaît pas sur le site (son nom commence par "_").
Copiez-le dans votre dossier, renommez la copie avec la date (ex. 2026-09-23.md), puis :
- title : la date et le sujet de la séance ;
- parent : EXACTEMENT le titre de votre page étudiant (docs/journal/votre-dossier/index.md).
-->

# AAAA-MM-JJ : sujet de la séance

**Séance :** planifiée / hors créneau · **Durée :** 2 h

## Fait

Ce que j'ai réalisé pendant la séance.

## Pourquoi

Les décisions prises et leurs raisons (mesures, essais, échanges avec l'équipe).

## Reste à faire

Les prochaines actions, et ce qui bloque éventuellement.

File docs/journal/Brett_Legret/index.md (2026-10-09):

---
layout: default
title: Brett_Legret
parent: Journal de bord
has_children: true
---

# Brett LEGRET

{: .a_modifier }
> Remplacez « Étudiant 2 » par votre prénom et votre nom, **dans le titre de la page
> (`title:`) et dans le `parent:` de chacune de vos séances** : c'est ce qui
> relie vos séances à votre page.

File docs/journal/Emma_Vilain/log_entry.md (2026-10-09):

---
layout: default
title: log_entry
parent: Emma_Vilain
---

## Entrée 1 : 23/09/2026

Découverte documentation des années précédentes : pour visualiser objectifs, la structure d'un robot principale, les composants principaux, ce que l'on peut améliorer ou reprendre des années précédentes.
Compréhension des attentes et règles de la coupe.
Recherches faites sur actionneurs pour robot principal, afin d'aider à sa conception. 

## Entrée 2 : 09/10/2026
Multi-fichier: 1 fichier par actionneurs gérer par un système Booléen

    *Objectifs: rester en modulaire: permet de travailler plus efficacement en équipe et d'avoir une meilleure visibilité sue le programme

Steps:

step 1: Mobilité du robot(rouler droit, tourner...ect);

step 2: Lidar(se repérer sur le plateau);

step 3: tirettes;

step 4: Actionneurs;

step 5: switch (sûrement utilisé avec step 4 et 6);

step 6: écran (selon temps restant);

    Attention: Aucun moyen de tester pour l'instant !!!

### Batterie de tests: 40 tests par valeur;

    info:plateau: 3m par 2m avec X: longueur, y: largeur;

Tests sur mobilité: (en relative/coordonnées par rapport à un emplacement/ puis en absolue/coordonnées géographique/)

Rouler droit: sur 10cm, 20cm, 50cm, 1m et plus;

Tourner: à 10°, 50°, 100°, 180° et 360°;

Serpentin: de droite à gauche et de gauche à droite;

Simulation de game.
|Test: Rouler droit                                                                |
|   :----------------------------------------------------------------------------  |
|     | long 10 |  20cm  |  30cm  |  50cm  |   1m   |   +    |        |marge erreur|  
|Tst 1|         |        |        |        |        |        |        |            |
|02   |         |        |        |        |        |        |        |            |
|03   |         |        |        |        |        |        |        |            |
|04   |         |        |        |        |        |        |        |            |
|05   |         |        |        |        |        |        |        |            |
|06   |         |        |        |        |        |        |        |            |
|07   |         |        |        |        |        |        |        |            |
|08   |         |        |        |        |        |        |        |            |
|09   |         |        |        |        |        |        |        |            |
|10   |         |        |        |        |        |        |        |            |
|11   |         |        |        |        |        |        |        |            |
|12   |         |        |        |        |        |        |        |            |
|13   |         |        |        |        |        |        |        |            |
|14   |         |        |        |        |        |        |        |            |
|15   |         |        |        |        |        |        |        |            |
|16   |         |        |        |        |        |        |        |            |
|17   |         |        |        |        |        |        |        |            |
|18   |         |        |        |        |        |        |        |            |
|19   |         |        |        |        |        |        |        |            |
|20   |         |        |        |        |        |        |        |            |
|21   |         |        |        |        |        |        |        |            |
|22   |         |        |        |        |        |        |        |            |
|23   |         |        |        |        |        |        |        |            |
|24   |         |        |        |        |        |        |        |            |
|25   |         |        |        |        |        |        |        |            |
|26   |         |        |        |        |        |        |        |            |
|27   |         |        |        |        |        |        |        |            |
|28   |         |        |        |        |        |        |        |            |
|29   |         |        |        |        |        |        |        |            |
|30   |         |        |        |        |        |        |        |            |
|31   |         |        |        |        |        |        |        |            |
|32   |         |        |        |        |        |        |        |            |
|33   |         |        |        |        |        |        |        |            |
|34   |         |        |        |        |        |        |        |            |
|35   |         |        |        |        |        |        |        |            |
|36   |         |        |        |        |        |        |        |            |
|37   |         |        |        |        |        |        |        |            |
|38   |         |        |        |        |        |        |        |            |
|39   |         |        |        |        |        |        |        |            |
|40   |         |        |        |        |        |        |        |            |

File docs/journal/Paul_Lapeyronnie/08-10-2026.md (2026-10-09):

---
layout: default
title: "08-10-2026 : lancement"
parent: Paul_Lapeyronnie
grand_parent: Journal de bord
---

# carte élec :
### je refait toute la carte en corrigeant les erreures que j'avais faites
### tout est remis a la grille, tou est alligner, je privilégie les zones plutot que des routes qui zigzag, la plus part des chauses sont sur la couche rouge

# dossier sponsor
### fait ça plutard
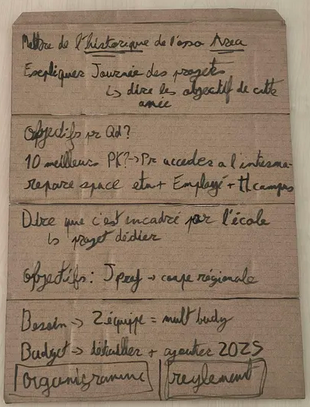
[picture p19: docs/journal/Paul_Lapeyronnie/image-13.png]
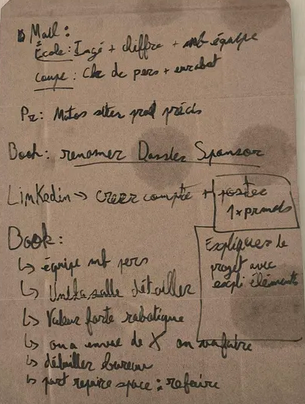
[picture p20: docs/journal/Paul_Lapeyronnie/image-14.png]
###

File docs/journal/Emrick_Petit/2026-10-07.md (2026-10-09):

---
layout: default
title: "2026-10-07 : Déployement de la documentation PAMI v1.0"
parent: Emrick_Petit
grand_parent: Journal de bord
---

# 2026-10-07 : Déployement de la documentation PAMI v1.0

**Type de séance :** Session de travail · **Durée :** <span><code style="color: blue;">3h (18h-21h)</code></span>

## Réalisé durant la scéance :

### Fin de défveloppement et déployement de la documentation PAMI :

J'ai terminé la page de documentation des PAMI à l'intention des premières années. Bien que le détail des composants soit encore manquant, le principal y est présent pour bien débuter.

(Lien vers la documentation PAMI)[https://unimakers.fr/CDR-2027/Documentation/Doc%20PAMI.html]

### Impression de bases Gridfinity pour la servante :

Dans le but de mieux ranger les outils dans la servante (et de virer définitivement la mousse), j'ai commencé à imprimer une base Gridfinity (non sans échecs de la part des imprimantes).

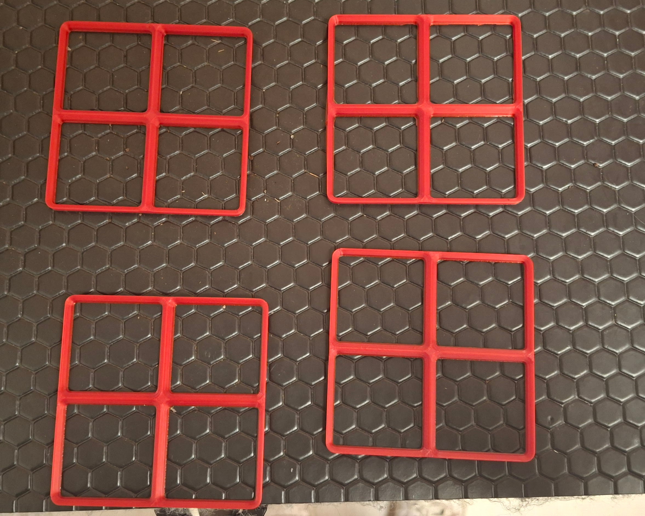
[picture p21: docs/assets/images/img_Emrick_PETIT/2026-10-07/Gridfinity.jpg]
Gridfinity


## Conclusion de la scéance :

Nous avons terminé par une réunion à propos de l'organisation des équipes, l'intégrartion progressive des premières années et la question des sponsorts. 

## A faire lors de la prochaine scéance :

| Type de tâche | Description | Priorité |
|---|---|---|
| Conception | Brainstorm sur la conception mécanique et stratégique des PAMI | 1 |
| Rangement | Terminer le système Gridfinity pour la servante | 2 |
| Conception | Brainstorm sur la nature du Graal | 3 |

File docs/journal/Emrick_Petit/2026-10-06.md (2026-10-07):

---
layout: default
title: "2026-10-06 : Création de la documentation PAMI"
parent: Emrick_Petit
grand_parent: Journal de bord
---

# 2026-10-06 : Création de la documentation PAMI

**Type de séance :** temps libre · **Durée :** <span><code style="color: blue;">3h</code></span>

## Réalisé durant la scéance :

En vue de préparer l'arrivé des premières années pour la session de travail du mercredi 2026-10-07, j'ai commencé de créer une page de documentation expliquant plus en détail le rôle des PAMI pour la CDR 2027 ainsi que les attendus lié à leur future conception par les I1.

## Conclusion de la scéance :

La documentation servira, je l'espère, de fil conducteur au I1 pour mieux comprendre ce qui sera attendu d'eux et permettra de regrouper les informations importantes concernant les besoins à répondre et les contraintes à respecter. J'espère aussi que les conseils que j'y ai ajouté leur seront utile.

## A faire lors de la prochaine scéance :

{: .info}
> La documentation sera à terminer le plus vite possible mais pourra être modifié par la suite en cas de besoin pour ajouter des précisions.
> Je ne l'ai pas encore déployé car elle est incomplète.

A faire pour la prochaine scéance planifiée (2026-10-09):

| Type de tâche | Description | Priorité |
|---|---|---|
| Organisation | Définir les attendus de chacun en terme de tâches | 1 |
| Rangement | Ranger le tiroir "outils" de la servante | 2 |

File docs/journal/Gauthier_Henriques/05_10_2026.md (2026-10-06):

---
layout: default
title: "05-10-2026 : Recherche sponsor"
parent: Gauthier_Henriques
grand_parent: Journal de bord
---

# 05-10-2026 : Recherche de sponsor

**Séance :** Contrat-d'étude · **Durée :** 1 h 30

## Fait

Texte d'appel sponsor :

> Bonjour , vous êtes bien l'entreprise [entreprise]
> Nous sommes une association étudiante de robotique basée sur Amiens.
> Nous participon à une compétition national de robotique rassemblant des centaines de jeunes.
> Notre objectif, est d'apprendre l'électronique, la mécanique, et l'automatisation à nos étudiants à travers cette compétition.
> Pour y participer nous avons besoin de financement, ou de matériel.

- 5 entreprise appelé, 6 mail (suivie et directe)

## A faire

- continuer de contacter les entreprises listé.
- Suivre les demandes faites

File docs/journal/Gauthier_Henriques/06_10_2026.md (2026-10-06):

---
layout: default
title: "06-10-2026 : Recherche sponsor"
parent: Gauthier_Henriques
grand_parent: Journal de bord
---

# 06-10-2026 : Recherche sponsor

**Séance :** Contrat-d'étude · **Durée :** 1 h 30

## Sponsor

- Suivi sur les contact fait précédemment

- nouveau contact : Cirly (fabriquant de carte électronique français), elsys-design (system embarqué)

- suivie par mail d'une demande au près de nos contact (RH actemium amiens) au sein de Vinci énergie

## ROBOT PRINCIPALE

- définition de la place de l'écran

Je compte mettre l'écran à l'horizontale afin de limiter les limites de nom d'option. Il vas être controlées à l'aide d'un bouton unique, 1 clique pour défiler et 2 pour sélectionner.

Le strois switch vont servir comme optionnages physique non négotiable au niveaux software, ainsi le options concernant lidar et stratégie ne peuvent pas fail à cause de l'écran.

### reste à faire

Je vais commencer le code avec un cahier de scharges bien définie :
- Il faut que le code soit adaptable de plusieurs façon, notament écran qui sera rajouté.
- Le code doit avoirr un lidar fonctionnelle, avec une option de triangulisation à l'aide de trois (ou 4) balise.

## PENSE-BÊTE

- Penser à suivre de près Vinci, de revérifier au près des contacts en attente.

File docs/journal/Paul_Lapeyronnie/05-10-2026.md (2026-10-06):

---
layout: default
title: "05-10-2026 : lancement"
parent: Paul_Lapeyronnie
grand_parent: Journal de bord
---

# contacte sponsors

j'ai une liste d'entreprise que j'avais faite avant et j'appelle les entreprises une a une.

voici ma trame a suivre pour les appelles:
- bonjour vous etes l'entreprise .......
nous sommes une association étudiante de robotique basé sur amiens nous participons a des compétition internationale de robotique rassemblant des centaines de jeunes.
notre objectif est d'aprendre l'éléctronique la mécanique et l'automatiqation a nos étudiants a travers cette compétition.
pour y participer nous avons besoin de financement ou du matériel.
puis répondre aux questions.

mail envoyé a :
- marion.idee@plastivaloire.com

# carte électronique

## déssouder carte de l'année dernière : 
- pour déssouder gros composant chiant mettre eteint en sur  plus, puis chauffer longtemps et enfin taper fort avec les pins vers le bas pour faire tomber
- pour petits composants, faire a la souflette a air chaud

## routage carte terminé :
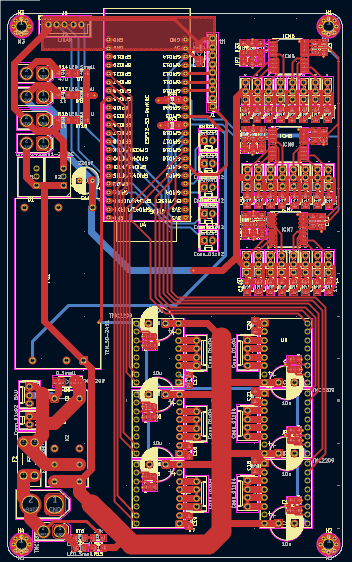
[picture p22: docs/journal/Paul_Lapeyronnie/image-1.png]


- pas sur que la partie sous l'ESP soit tres belle mais il faudrais changer tous les pins de l'ESP et j'ai pas supper envie

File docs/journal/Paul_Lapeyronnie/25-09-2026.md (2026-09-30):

---
layout: default
title: "25-09-2026 : lancement"
parent: Paul_Lapeyronnie
grand_parent: Journal de bord
---

# 25-09-2026 : lancement ,des équipes

{: .a_supprimer }
> Exemple de séance : supprimez ce fichier quand vous avez créé vos propres séances.

**Séance :** planifiée · **Durée :** 2 h

## Fait

- explications des roles que chaqu'un doit prendre
- explication des objectifs de chaque groupe
- continuer la carte élec

## Pourquoi

- lancer l'équipe sur la coupe, séparrer les roles et donner les directives de groupe pour l'année
- permetre a chaqu'un de savoir quoi faire
- faire rouler le robot 

## Reste à faire

- treminer la carte

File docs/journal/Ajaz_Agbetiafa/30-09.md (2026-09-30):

---
layout: default
title: Ajaz_Agbetiafa
parent: Journal de bord
has_children: true
---

# __Done__

> rewatched CDR's video to memorize the rules
>
> started writing on the journal
>
> initial push :v:

## __what needs to be done__

> - finding a precise thing to work on for the PAMI
> - look at all existing files on the previous cdrs
> - ( oscar's repo ) ; [MakerspaceAmiens](https://doc.makerspace-amiens.fr) 

### *infos*

markdown syntax : [don't](https://www.markdownguide.org/basic-syntax/)

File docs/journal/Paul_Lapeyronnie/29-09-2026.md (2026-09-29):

---
layout: default
title: "29-09-2026 : lancement"
parent: Paul_Lapeyronnie
grand_parent: Journal de bord
---

# 29-09-2026 : écriture les objectifs + terminer schématique carte principale

## Fait

- modif repo objectifs
- terminer schématique la carte (rési TBD + ecran)
- comencer routage carte
## Pourquoi

pour faire rouler et fonctionner le robot mdr

## Reste à faire

terminer le routage de la carte

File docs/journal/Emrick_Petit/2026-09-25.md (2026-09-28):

---
layout: default
title: "2026-09-25 : Démontage des PAMI et rangement du Robotlab"
parent: Emrick_Petit
grand_parent: Journal de bord
---

# 2026-09-25 : Démontage des PAMI et rangement du Robotlab

**Type de séance :** planifiée + temps libre · **Durée :** <span><code style="color: blue;">8 h (9h-17h30)</code></span>

## Réalisé durant la scéance :

### Démontage des PAMI de la CDR 2026 :

J'ai démonté les PAMI de la CDR 2026 afin d'en récupérer les composants pour les réutiliser dans les PAMI 2027.

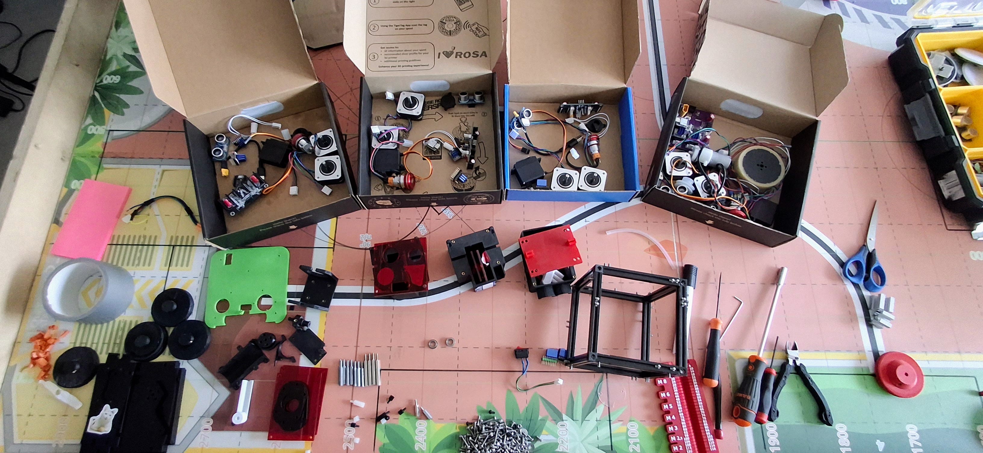
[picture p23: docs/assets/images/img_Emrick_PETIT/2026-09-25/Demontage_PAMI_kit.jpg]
Démontage des PAMI 2025 et kits de composants pour les PAMI 2026


### Création de "kits PAMI" :

J'ai rassemblé une liste de composants standardisés pour la conception des PAMI 2027, notamment à l'intention des I1.
Chaque set possède sa boite. Pour l'instant, il y a 3 kits PAMI complets et un kit pour le PAMI Graal dans le cas où on voudra faire un Graal actif.

Contenu des Kits PAMI :

| Composant | Quantité | Remarque |
|---|---|---|
| Step-motors| 2 | |
| Servomoteur| 1 | Changement pour sevomoteurs pour des plus gros<br>mieux adaptés aux nouvelles contraintes de taille |
| Bouton d'arrêt d'urgence (BAU) | 1 | |
|Télémètre à ultrason | 1 | Ont déjà les PIN intégrés |
|"Tirette" aimantée | 1 | Vérifier leur état de fonctionnement (certaines sont abimées)|
| Support pour "Tirette" | 1 | À remodéliser selon les besoins |
| Carte électronique de PAMI 2026 | 1 | Pré-assemblée |
| Module ESP-32 | 1 | Fixable directement sur la carte PAMI 2026 |
| Modules TMC-2209 | 2 | Fixables directement sur la carte PAMI 2026 |

### Rangement du Robotlab et tri d'une partie de visserie :

Le Robotlab se doit de rester un espace où il est possible de travailler librement. J'ai donc rangé une grande partie du matériel et des vis dispersées. Suite au démontage des PAMI, j'ai notamment dû trier et ranger les composants (soit dans les kits soit dans leur rangement défini) et les vis utilisées. Enfin, j'ai marqué les boites de rangement afin de pouvoir en connaitre le contenue d'un seul coup d'oeil.

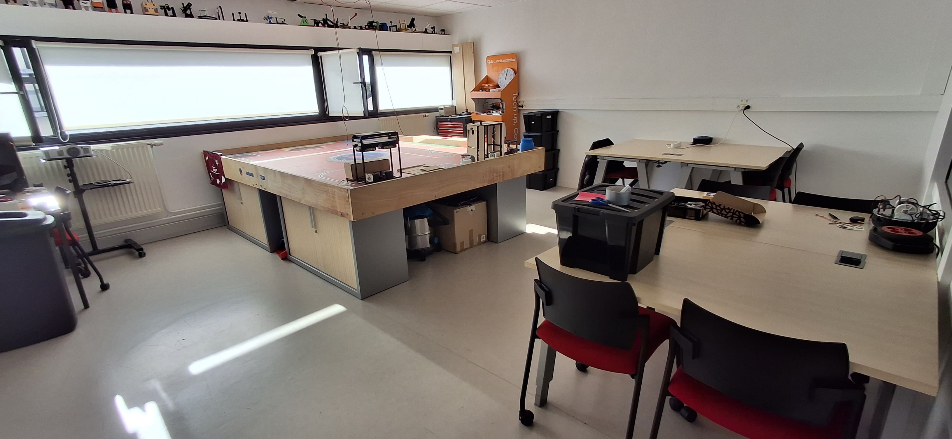
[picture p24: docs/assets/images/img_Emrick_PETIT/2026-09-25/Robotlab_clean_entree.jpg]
Robotlab rangé vue depuis l'entrée

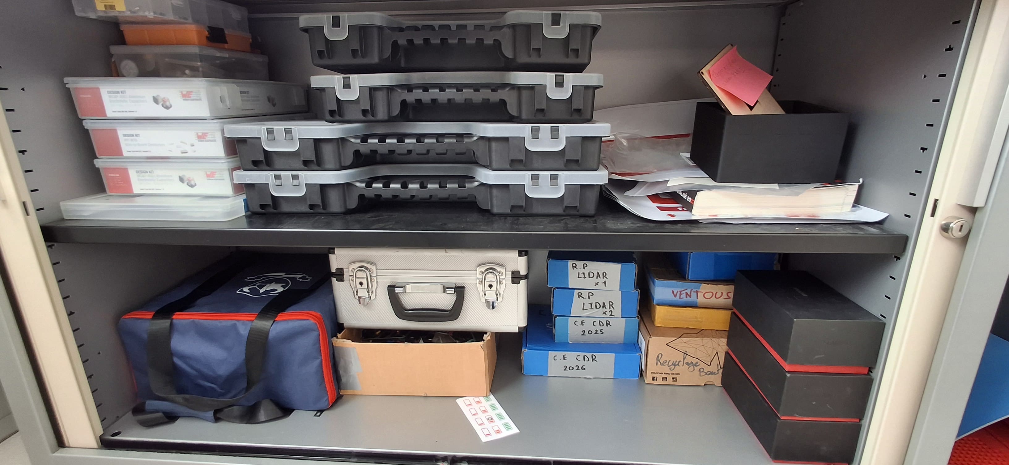
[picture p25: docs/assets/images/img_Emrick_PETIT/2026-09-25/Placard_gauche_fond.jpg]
Placard au fond gauche rangé

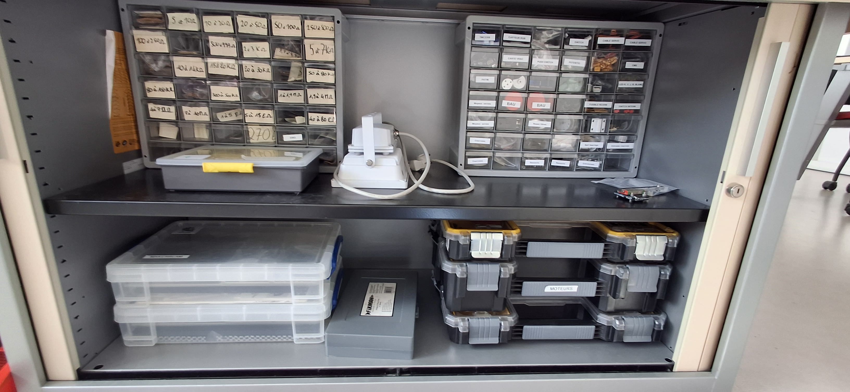
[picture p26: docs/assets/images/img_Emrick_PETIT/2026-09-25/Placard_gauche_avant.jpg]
Placard au avant gauche rangé

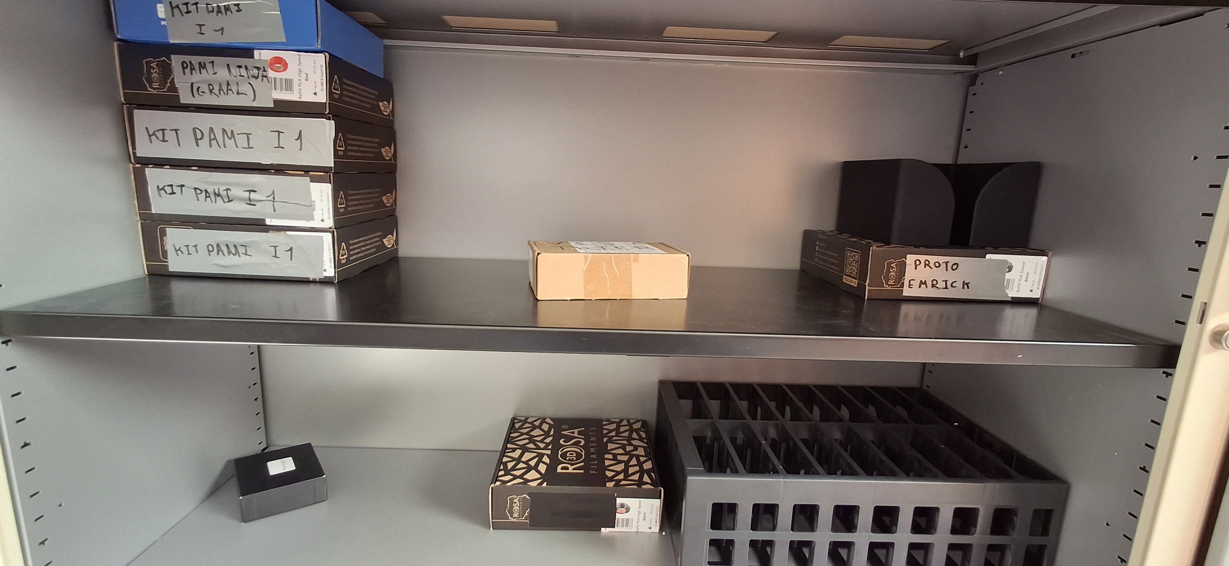
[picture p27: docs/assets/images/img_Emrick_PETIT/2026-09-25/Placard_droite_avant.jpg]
Placard au avant droite rangé


### Réalisation d'un patron d'éléments de jeux dépliable :

J'ai découpé un patron d'élément de jeux afin d'avoir un répère physique pour la modélisation en vue d'une découpe au laser plus précise. À noter que le patron en lui même est sensé être aux bonnes dimentions (32mmX11mmX11mm) mais que suite  à une erreur de marge par rapport à la bordure du carte, j'ai adapté le patron de deux manières différentes pour les bouts, l'une avec deux carré de 11mmX11mm et l'autre avec quatre rabats se rejoignant au centre. Cette option prend moins de place mais demande plus de précision pour bien les fixer ensuite.

## Conclusion de la scéance :

Le nettoyage des locaux ainsi que la création des kits PAMI et d'un modèle pour les éléments de jeux sont vont permettre de commencer le projet sur une base saine. Le but sera de garder le Robotlab le plus rangé posssible afin d'éviter la perte de matériel et d'espace de travail.

## A faire lors de la prochaine scéance :

| Type de tâche | Description | Priorité |
|---|---|---|
| Organisation | Définir les attendus de chacun en terme de tâches | 1 |
| Documentation | Créer une documentation afin d'expliquer d'initier les I1<br>au fonctionnement d'un PAMI et aux kits qu'ils utiliseront | 2 |
| Rangement | Ranger le tiroir "outils" de la servante | 3 |

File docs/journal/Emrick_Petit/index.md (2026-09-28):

---
layout: default
title: Emrick_Petit
parent: Journal de bord
has_children: true
---

# Journal de bord d'Emrick PETIT

{: .info }
> Cette page d'accueil est dédiée au travail réalisé par **Emrick PETIT** dans le cadre de la Coupe de France de Robotique (CDR 2027)

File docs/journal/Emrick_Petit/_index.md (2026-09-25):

---
layout: default
title: Emrick_Petit
parent: Journal de bord
has_children: true
---

# Journal de bord d'Emrick PETIT

{: Information }
> Cette page d'accueil est dédiée aux projets d'Emrick PETIT dans le cadre de la Coupe de France de Robotique (CDR 2027)
> 
> relie vos séances à votre page.

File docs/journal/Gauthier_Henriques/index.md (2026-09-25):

---
layout: default
title: Gauthier_Henriques
parent: Journal de bord
has_children: true
---

# Étudiant 1

{: .a_modifier }
> Remplacez « Étudiant 1 » par votre prénom et votre nom, **dans le titre de la page
> (`title:`) et dans le `parent:` de chacune de vos séances** : c'est ce qui
> relie vos séances à votre page.

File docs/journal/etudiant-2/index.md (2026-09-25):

---
layout: default
title: Étudiant 2
parent: Journal de bord
has_children: true
---

# Étudiant 2

{: .a_modifier }
> Remplacez « Étudiant 2 » par votre prénom et votre nom, **dans le titre de la page
> (`title:`) et dans le `parent:` de chacune de vos séances** : c'est ce qui
> relie vos séances à votre page.

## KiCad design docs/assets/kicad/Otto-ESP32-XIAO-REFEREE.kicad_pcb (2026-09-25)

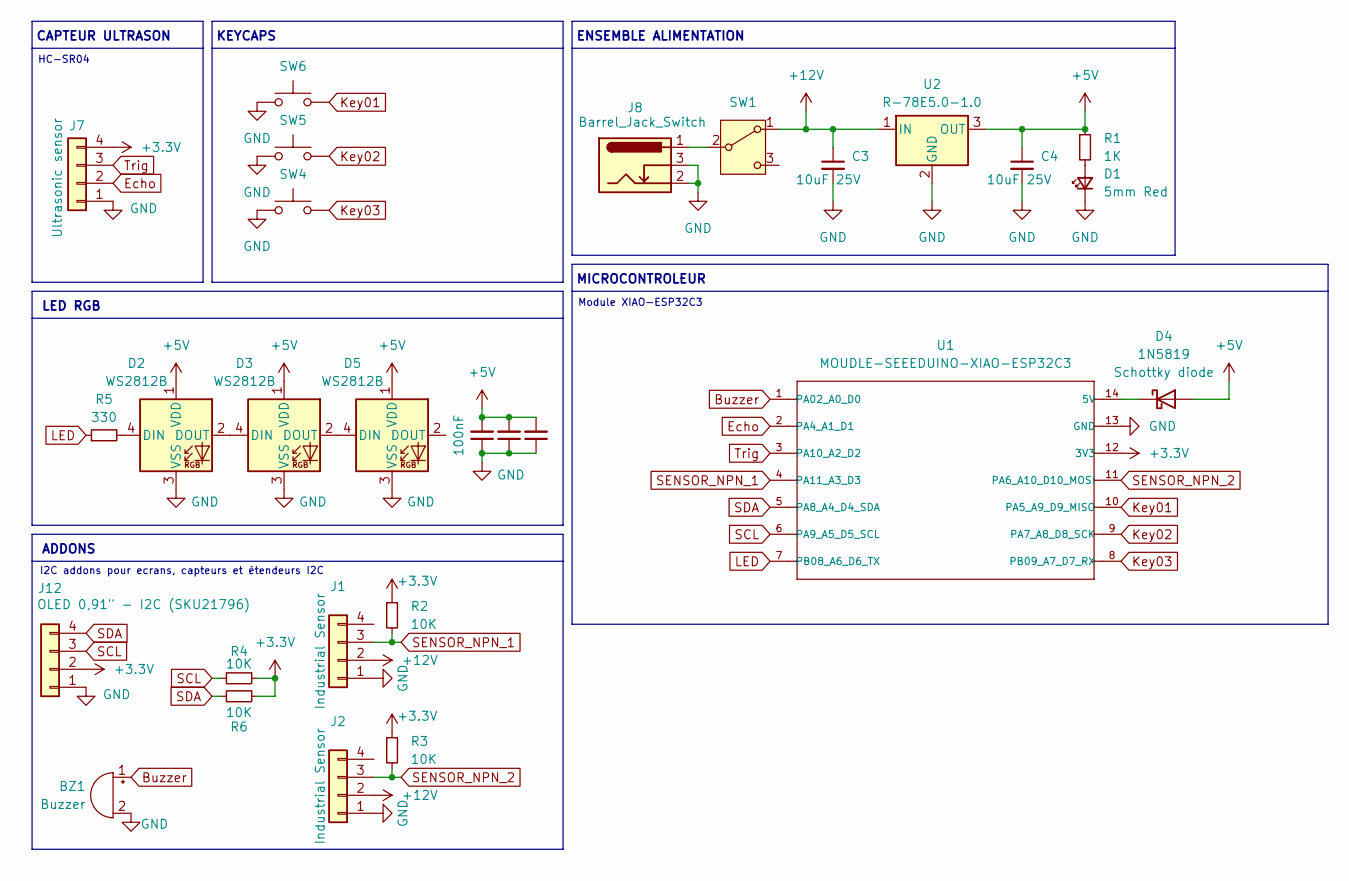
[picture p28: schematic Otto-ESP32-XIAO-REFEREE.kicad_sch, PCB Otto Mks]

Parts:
BZ1: Buzzer; Buzzer_12x9.5RM7.6
C3, C4: 10uF 25V; C_Disc_D6.0mm_W2.5mm_P5.00mm
C5, C6, C7: 100nF; C_1206_3216Metric_Pad1.33x1.80mm_HandSolder
D1: 5mm Red; LED_1206_3216Metric_Pad1.42x1.75mm_HandSolder
D2, D3, D5: WS2812B; LED_WS2812B_PLCC4_5.0x5.0mm_P3.2mm
D4: 1N5819; D_A-405_P7.62mm_Horizontal
J1, J2: Industrial Sensor; Molex_KK-254_AE-6410-04A_1x04_P2.54mm_Vertical
J7: Ultrasonic sensor; PinSocket_1x04_P2.54mm_Vertical
J8: Barrel_Jack_Switch; BarrelJack_Horizontal
J12: OLED 0,91" - I2C (SKU21796); PinSocket_1x04_P2.54mm_Vertical
R1: 1K; R_1206_3216Metric_Pad1.30x1.75mm_HandSolder
R2, R3, R4, R6: 10K; R_1206_3216Metric_Pad1.30x1.75mm_HandSolder
R5: 330; R_1206_3216Metric_Pad1.30x1.75mm_HandSolder
SW1: SW_SPDT; SW_100SP1T1B4M2QE
SW4, SW5, SW6: CherryMX; SW_Cherry_MX_1.00u_PCB
U1: MOUDLE-SEEEDUINO-XIAO-ESP32C3; XIAO-ESP32C3-DIP
U2: R-78E5.0-1.0; Converter_DCDC_RECOM_R-78E-0.5_THT

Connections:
+3.3V: J7.4, J12.2, R2.1, R3.1, R4.1, R6.1, U1.12 (3V3)
+5V: C4.1, C5.2, C6.2, C7.2, D2.1 (VDD), D3.1 (VDD), D4.2 (A), D5.1 (VDD), R1.1, U2.3 (OUT)
+12V: C3.1, J1.2, J2.2, SW1.1 (A), U2.1 (IN)
Buzzer: BZ1.1 (+), U1.1 (PA02_A0_D0)
Echo: J7.2, U1.2 (PA4_A1_D1)
GND: BZ1.2 (-), C3.2, C4.2, C5.1, C6.1, C7.1, D1.1 (K), D2.3 (VSS), D3.3 (VSS), D5.3 (VSS), J1.1, J2.1, J7.1, J8.2, J8.3, J12.1, SW4.1, SW5.1, SW6.1, U1.13 (GND), U2.2 (GND)
Key01: SW6.2, U1.10 (PA5_A9_D9_MISO)
Key02: SW5.2, U1.9 (PA7_A8_D8_SCK)
Key03: SW4.2, U1.8 (PB09_A7_D7_RX)
LED: R5.1, U1.7 (PB08_A6_D6_TX)
unnamed: D1.2 (A), R1.2
unnamed: D2.4 (DIN), R5.2
unnamed: D2.2 (DOUT), D3.4 (DIN)
unnamed: D3.2 (DOUT), D5.4 (DIN)
unnamed: D4.1 (K), U1.14 (5V)
unnamed: J8.1, SW1.2 (B)
SCL: J12.3, R4.2, U1.6 (PA9_A5_D5_SCL)
SDA: J12.4, R6.2, U1.5 (PA8_A4_D4_SDA)
SENSOR_NPN_1: J1.3, R2.2, U1.4 (PA11_A3_D3)
SENSOR_NPN_2: J2.3, R3.2, U1.11 (PA6_A10_D10_MOSI)
Trig: J7.3, U1.3 (PA10_A2_D2)

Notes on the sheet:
HC-SR04
CAPTEUR ULTRASON
LED RGB
ADDONS
ENSEMBLE ALIMENTATION
KEYCAPS
Module XIAO-ESP32C3
I2C addons pour ecrans, capteurs et étendeurs I2C
MICROCONTROLEUR

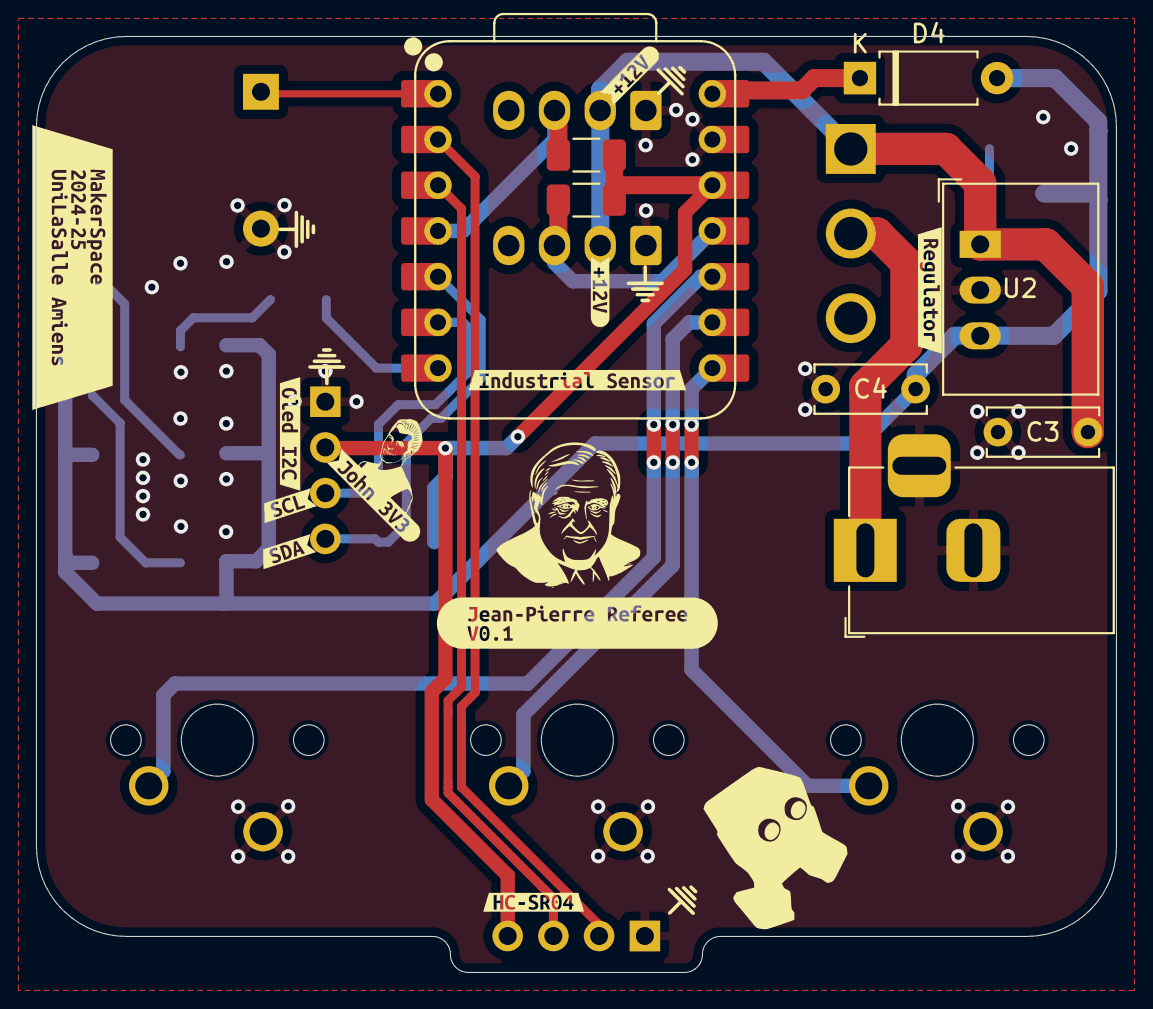
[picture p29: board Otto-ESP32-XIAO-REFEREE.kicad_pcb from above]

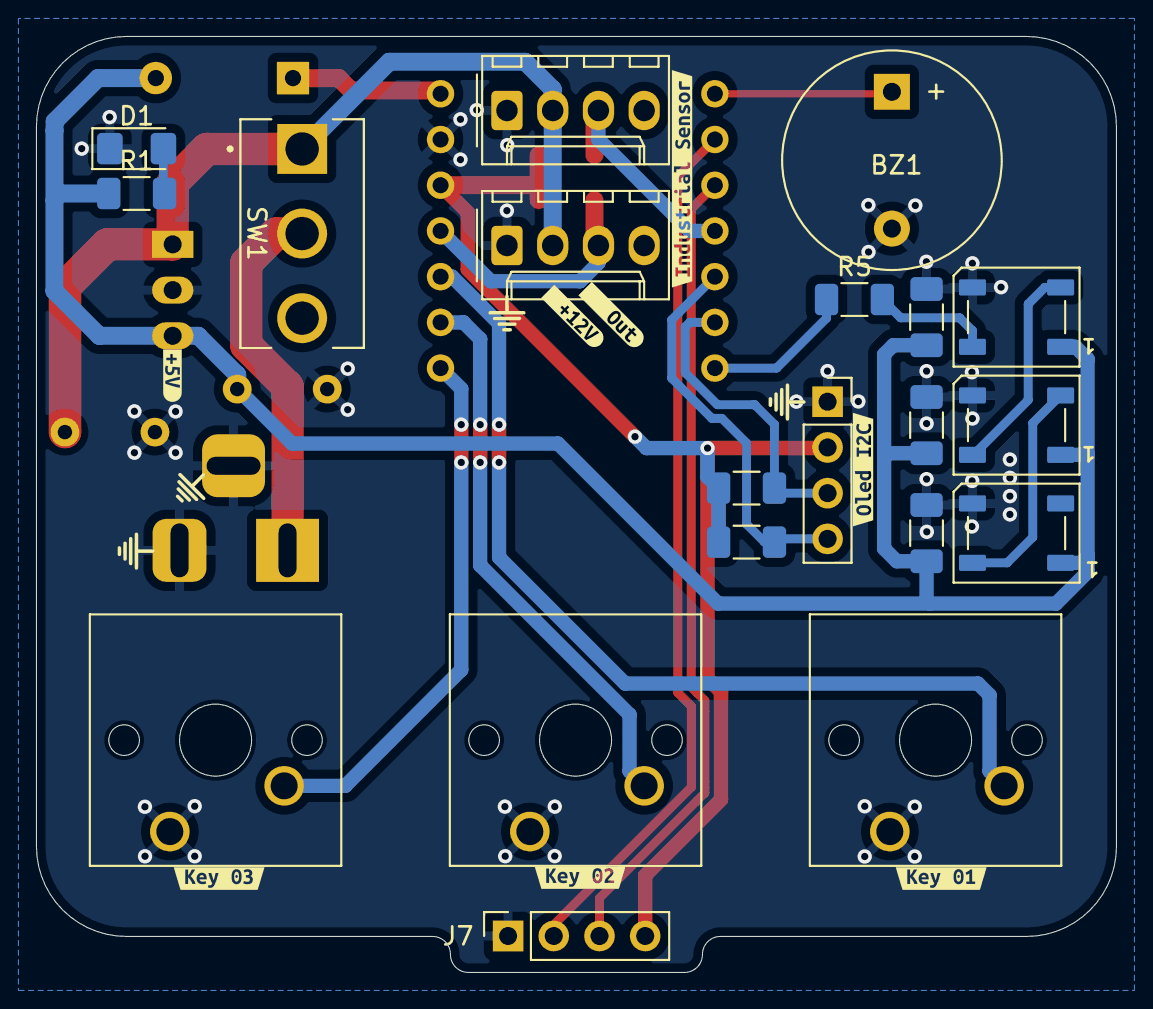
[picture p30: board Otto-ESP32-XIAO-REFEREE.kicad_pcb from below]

Board: 2 copper layers, 60.0 x 52.0 mm, 47 parts (28 on the bottom side), 21 nets.

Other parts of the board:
kibuzzard-66E45BAB: G***; kibuzzard-66E45BAB
kibuzzard-66E46157: G***; kibuzzard-66E46157
kibuzzard-67E17B13: G***; kibuzzard-67E17B13
kibuzzard-67E17C5A, kibuzzard-67E17C5A#2: G***; kibuzzard-67E17C5A
kibuzzard-67E17C70: G***; kibuzzard-67E17C70
kibuzzard-67E17CA6: G***; kibuzzard-67E17CA6
kibuzzard-67E17CB8, kibuzzard-67E17CB8#2: G***; kibuzzard-67E17CB8
kibuzzard-67E17911: G***; kibuzzard-67E17911
kibuzzard-67E17954: G***; kibuzzard-67E17954
kibuzzard-67EAB5AA: G***; kibuzzard-67EAB5AA
kibuzzard-67EAB5C2: G***; kibuzzard-67EAB5C2
kibuzzard-67EAB5C7: G***; kibuzzard-67EAB5C7
kibuzzard-67EAB37B: G***; kibuzzard-67EAB37B
kibuzzard-67EAB421: G***; kibuzzard-67EAB421
kibuzzard-6707C6B3: G***; kibuzzard-6707C6B3
kibuzzard-6765451E: G***; kibuzzard-6765451E
kibuzzard-67654523: G***; kibuzzard-67654523

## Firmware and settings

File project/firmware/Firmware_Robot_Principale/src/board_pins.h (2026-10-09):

// Board pinout: exact mirror of the KiCad schematic "carte principale" (ESP32-S3-DevKitC-1, U4).
// Only edit this file when the PCB changes. What each slot is USED for lives in robot_config.h.
// -1 = placeholder, pin not frozen yet; the current schematic GPIO is given in the comment.

#pragma once

#include <stdint.h>

// ---------------------------------------------------------------------------
// Stepper drivers (TMC2209 U5..U10, 24V, STEP/DIR only: UART, DIAG and INDEX not wired)
// Slot index used in robot_config.h = schematic number - 1.
//
//   slot | driver | motor connector | microstep jumpers (MS1 / MS2)
//   -----+--------+-----------------+------------------------------
//     0  |   U5   |       J4        |   JP1  / JP2
//     1  |   U6   |       J7        |   JP3  / JP16
//     2  |   U7   |       J9        |   JP17 / JP18
//     3  |   U8   |       J8        |   JP4  / JP5
//     4  |   U9   |       J10       |   JP6  / JP19
//     5  |   U10  |       J11       |   JP20 / JP21
//
// Note: U7 drives J9 and U8 drives J8 (crossed on the schematic).
// ---------------------------------------------------------------------------
#define STEPPER_SLOT_COUNT 6

#define STEP_1_PIN -1 // schematic: GPIO14
#define DIR_1_PIN -1  // schematic: GPIO17
#define STEP_2_PIN -1 // schematic: GPIO18
#define DIR_2_PIN -1  // schematic: GPIO21
#define STEP_3_PIN -1 // schematic: GPIO35
#define DIR_3_PIN -1  // schematic: GPIO36
#define STEP_4_PIN -1 // schematic: GPIO37
#define DIR_4_PIN -1  // schematic: GPIO38 (onboard RGB LED on DevKitC-1 v1.1)
#define STEP_5_PIN -1 // schematic: GPIO15
#define DIR_5_PIN -1  // schematic: GPIO16
#define STEP_6_PIN -1 // schematic: GPIO47
#define DIR_6_PIN -1  // schematic: GPIO48 (onboard RGB LED on DevKitC-1 v1.0)

// Shared ~EN of the 6 drivers, active LOW.
// schematic: GPIO45. GPIO45 is a strapping pin (flash voltage): a pull-up on this
// line at boot selects 1.8 V flash and the board won't start. Move it before freezing.
#define MOTORS_EN_PIN -1
#define MOTORS_EN_ACTIVE_LOW true

// TMC2209 standalone microstepping, set by the solder jumpers (B = 3V3, A = GND):
//   MS1=0 MS2=0 -> 8   |   MS1=1 MS2=0 -> 2   |   MS1=0 MS2=1 -> 4   |   MS1=1 MS2=1 -> 16

// ---------------------------------------------------------------------------
// Power
// ---------------------------------------------------------------------------
#define EN_5VP_PIN -1 // ON/OFF of the 5VP converter PS1 (servos/pumps), schematic: GPIO3

// ---------------------------------------------------------------------------
// I2C bus (frozen): 3x PCF8574T ICM6..ICM8 + J2 connector, 4.7k pull-ups on board
// ---------------------------------------------------------------------------
#define I2C_SDA_PIN 9
#define I2C_SCL_PIN 8

// PCF8574T address = 0x20 + (A2 A1 A0). Each Ax has a 4.7k pull-down; soldering its
// jumper sets it to 1. With no jumper soldered all three answer on 0x20 -> conflict.
#define PCF_COUNT 3
#define PCF_ICM6_ADDR -1 // jumpers JP7 (A0), JP8 (A1), JP9 (A2)
#define PCF_ICM7_ADDR -1 // jumpers JP10 (A0), JP11 (A1), JP12 (A2)
#define PCF_ICM8_ADDR -1 // jumpers JP13 (A0), JP14 (A1), JP15 (A2)
// ~INT outputs are only pulled up, not wired to the ESP32: inputs must be polled.

// ---------------------------------------------------------------------------
// Actuator connectors "Servo1".."Servo24": 5VP + GND + one signal line on a PCF8574 output.
// ICM6 -> connectors 1..8, ICM7 -> 9..16, ICM8 -> 17..24.
// Inside each group the wiring is interleaved, identical on the 3 PCF:
//   connector in group : 1  2  3  4  5  6  7  8
//   PCF output         : P1 P3 P5 P7 P0 P2 P4 P6
// For connector n (1..24): pcf = (n - 1) / 8, bit = ACTUATOR_PCF_BIT[(n - 1) % 8]
// ---------------------------------------------------------------------------
#define ACTUATOR_CONNECTOR_COUNT 24
#define ACTUATORS_PER_PCF 8
const uint8_t ACTUATOR_PCF_BIT[ACTUATORS_PER_PCF] = {1, 3, 5, 7, 0, 2, 4, 6};

// ---------------------------------------------------------------------------
// TFT screen (J1, SPI, no reset line on the schematic)
// ---------------------------------------------------------------------------
#define TFT_MISO_PIN -1 // "sdo", schematic: GPIO7
#define TFT_MOSI_PIN -1 // "sdi", schematic: GPIO11
#define TFT_SCK_PIN -1  // "sck", schematic: GPIO10
#define TFT_DC_PIN -1   // "dc",  schematic: GPIO12
#define TFT_CS_PIN -1   // "cs",  schematic: GPIO13

// ---------------------------------------------------------------------------
// Inputs (contact to GND, no external pull-up: use INPUT_PULLUP)
// ---------------------------------------------------------------------------
#define TIRETTE_PIN -1  // starting cord, "tir", schematic: GPIO2
#define BUTTON_PIN -1   // push button, "bu", schematic: GPIO4
#define SWITCH_1_PIN -1 // "sw1", schematic: GPIO5
#define SWITCH_2_PIN -1 // "sw2", schematic: GPIO6
#define SWITCH_3_PIN -1 // "sw3", schematic: GPIO1
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

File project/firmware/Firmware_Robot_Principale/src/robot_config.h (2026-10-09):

// Robot configuration: what each board slot is used for, and the tuning values.
// Pins come from board_pins.h; this file changes every time an actuator is tried.
// -1 = placeholder, not tuned yet.

#pragma once

#include <stdint.h>
#include "board_pins.h"

// Serial debug output
#define DEBUG_SERIAL true

// match duration
#define MATCH_DURATION 100 // in seconds

// ---------------------------------------------------------------------------
// Stepper slots: one line per TMC2209 slot (see the slot table in board_pins.h)
// ---------------------------------------------------------------------------
struct StepperSlot {
    int  stepPin;
    int  dirPin;
    bool inverted;        // true if the motor turns the wrong way
    int  stepsPerRev;     // full steps per motor revolution (200 for a 1.8 deg motor)
    int  microsteps;      // must match the slot's MS1/MS2 solder jumpers
    int  maxSpeedHz;      // for setSpeedInHz(), in steps/s
    int  accelerationHz2; // for setAcceleration(), in steps/s^2
};

const StepperSlot STEPPER_SLOTS[STEPPER_SLOT_COUNT] = {
    // stepPin     dirPin     inverted  stepsPerRev  microsteps  maxSpeedHz  accelerationHz2
    {STEP_1_PIN, DIR_1_PIN, false,    -1,          -1,         -1,         -1}, // slot 0
    {STEP_2_PIN, DIR_2_PIN, false,    -1,          -1,         -1,         -1}, // slot 1
    {STEP_3_PIN, DIR_3_PIN, false,    -1,          -1,         -1,         -1}, // slot 2
    {STEP_4_PIN, DIR_4_PIN, false,    -1,          -1,         -1,         -1}, // slot 3
    {STEP_5_PIN, DIR_5_PIN, false,    -1,          -1,         -1,         -1}, // slot 4
    {STEP_6_PIN, DIR_6_PIN, false,    -1,          -1,         -1,         -1}, // slot 5
};

// ---------------------------------------------------------------------------
// Wheels: always on slots 0 and 1. Slots 2..5 are free for actuators.
// ---------------------------------------------------------------------------
#define WHEEL_LEFT_SLOT 0
#define WHEEL_RIGHT_SLOT 1

static_assert(WHEEL_LEFT_SLOT == 0 || WHEEL_LEFT_SLOT == 1, "WHEEL_LEFT_SLOT must be 0 or 1");
static_assert(WHEEL_RIGHT_SLOT == 0 || WHEEL_RIGHT_SLOT == 1, "WHEEL_RIGHT_SLOT must be 0 or 1");
static_assert(WHEEL_LEFT_SLOT != WHEEL_RIGHT_SLOT, "Both wheels cannot use the same slot");

// ---------------------------------------------------------------------------
// LIDAR LD06 filtering (see setDistanceRange / setAngleRange / setIntensityThreshold)
// Set real values before calling enableFiltering(): the library stores them unsigned,
// so -1 would turn into 65535 / 255 and filter out every point.
// ---------------------------------------------------------------------------
#define LD06_MIN_DISTANCE -1        // in mm
#define LD06_MAX_DISTANCE -1        // in mm
#define LD06_MIN_ANGLE -1           // in degrees
#define LD06_MAX_ANGLE -1           // in degrees
#define LD06_INTENSITY_THRESHOLD -1 // 0-255
#define LD06_UPSIDE_DOWN false

// Lidar position relative to the robot center (see setOffsetPosition)
#define LD06_OFFSET_X -1     // in mm
#define LD06_OFFSET_Y -1     // in mm
#define LD06_OFFSET_ANGLE -1 // in degrees

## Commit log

2026-09-25 Add initial journal entry for actuator design concept
2026-09-28 Esthetic modification : > Created the "info" callout and modified the colors > Started the homepage's personalisation with titles, "onshape" button turned green, 3D modele of the robot instead of the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
2026-09-29 lol
    mais nan je rigole :
    ajout des objectifs de la coupe + supression Enzo (rip enzo)
2026-10-07 Add configuration file for robot firmware with pin definitions and settings
2026-10-07 Add LD06 Lidar driver implementation and configuration header
2026-10-09 Add stepper motor inversion configuration and clean up main.cpp
2026-10-09 Conception initiale de l’actionneur
2026-10-09 Add configuration files for robot firmware: board_pins.h and robot_config.h
2026-10-09 Add static assertion for unique I2C addresses in board_pins.h
2026-10-12 Update platformio.ini and board_pins.h for PCA9685 configuration; add PWM settings in robot_config.h
2026-10-12 Add actuator management and match timing functionality
    - Implement actuator classes for stepper, servo, and pump actuators.
    - Introduce match timer functions to manage match duration and state.
    - Create configuration checks for stepper slots and initialize PCA9685 drivers.
2026-10-12 Change MATCH_DURATION type from seconds to milliseconds. passed type from int to an UL
2026-10-12 Add journal entry
    Documented steps and tests for robot mobility and actuator management.
2026-10-12 MAJ 09-10 et creation session gestion de projet 12-09
2026-10-12 Add journal entry for 23-09-2026
    Added a new journal entry for 23/09/2026 detailing previous documentation review and actuator research for the main robot design.
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2026-10-12 changé noms + retrouvé les images
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2026-10-12 Add I2C scanning functionality and configuration updates
    - Introduced a new I2C scanning function in main.cpp and test1_I2C.cpp
    - Added serial communication setup for debugging
    - Updated platformio.ini with monitor speed
    - Created test1_I2C.cpp for testing I2C devices
    - Added empty test2_pca.cpp file for future development
2026-10-12 Refactor actuator and board pin definitions for clarity and update PCA addresses
2026-10-12 Add tests for I2C scanning, PCA9685 servo driver, stepper actuators, and wheel movement
2026-10-12 :v: polissage ( y'avait un defaut sur la page web)
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2026-10-13 Added space between separating lines in week recap (Fused title styles with the line before it)
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2026-10-16 ajout de la seance 09-23 et amelioration de la fomr des autres seance
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2026-10-19 Refactor stepper driver configuration and LD06 LIDAR integration
    - Updated board_pins.h to reflect changes in stepper driver configuration, reducing the number of drivers from 6 to 4 and adjusting pin assignments accordingly.
    - Modified ld06.cpp and ld06.h to improve documentation and clarify the usage of the LD06 LIDAR driver, including changes to the initialization process and data handling.
    - Enhanced match timer functionality in match.cpp and match.h, ensuring accurate timing and logging during match events.
    - Adjusted robot_config.h to align with the new stepper configuration, limiting actuator slots to 2.
    - Improved steppers.cpp and steppers.h to support the new configuration and ensur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
2026-10-21 Add configuration header for SIMA (PAMI) pin definitions
2026-10-21 Refactor motor pin definitions and servo control test
2026-10-21 - Added journal entries 19, 20 and 21-10-2026 - Added 2026-10-21 meeting notes - Updated firmware doc for PAMI - Created config.h in PAMI firmware for PIN management and made a first try on code
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2026-10-23 ajourt de la reparation de l'enceinte et de la decouverte plus pousser de l'outils
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2026-10-23 Séance sur la boîte à pami du 23-10-2026
2026-10-26 Corrected name errors leading to pcb and schematics not being found for PAMI.md
2026-11-04 Add journal entry for 2026-11-04: Electronics and sponsor responses
    - Documented the soldering of the head electronic board for robot operation.
    - Included responses from sponsors JLCPCB, CIT Dessaint, and Crédit Agricole.
    - Added a section for questions from JLCPCB regarding logo placement and t-shirts.
2026-11-06 Added RB_esp-32-s3 firmware
    Add LD06 LIDAR driver and related components
    - Implemented LD06 LIDAR driver in ld06.h and ld06crc.h, enabling communication with the LIDAR sensor.
    - Added match timer functionality in match.cpp and match.h to manage match duration and state.
    - Created PCF8574 driver in pcf8574.cpp and pcf8574.h for I2C communication with GPIO expander.
    - Defined robot configuration parameters
    in robot_config.h, including stepper motor settings and LIDAR filtering options.
    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
2026-11-06 Add new journal entries and updated firmware for PAMI
    - Added journal entry for 2026-11-04 detailing stepper programming.
    - Added journal entry for 2026-11-06, addressing stepper-servo interference issues.
    - Added a meeting report template for future use.
    - Updated configuration files to correct pin assignments and enhance motor control.
    - Implemented distance-based movement functions in main program for improved functionality.
    - PAMI Firmware now functional
2026-11-06 Update configuration and enhance motor control functions
    - Added favicon to configuration file.
    - Improved distance and angle calculation functions for motor movement.
    - Simplified movement logic in `go` function.
    - Implemented `turn` function for rotation control.
2026-11-09 Add journal entry for 2026-11-06 detailing head card and ESP32-S3 code
2026-11-12 corrections sur les journaux du 06 et 05
